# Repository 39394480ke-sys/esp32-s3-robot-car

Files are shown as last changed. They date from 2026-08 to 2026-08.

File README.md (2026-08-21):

# ESP32-S3 Robot Car

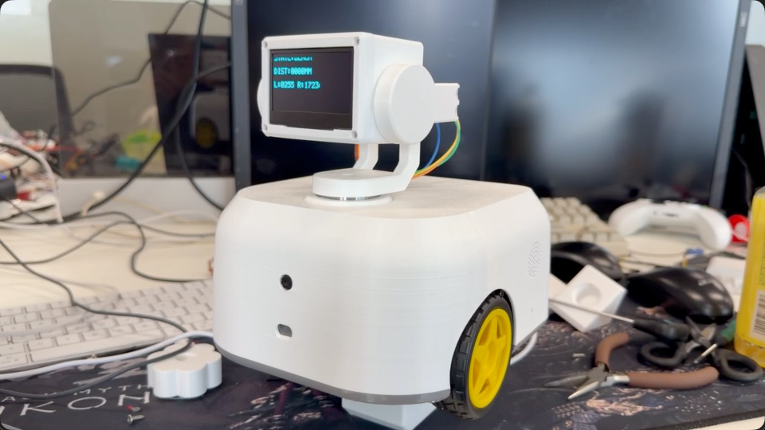
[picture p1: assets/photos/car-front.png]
ESP32-S3 小车实物正面


这是当前 ESP32-S3 双轮机器人小车的硬件与机械基线资料库，用于后续重新开发控制软件。仓库记录已经装配过的实物、供电与接口、机械装配、接线方法和硬件验证结论。

## 仓库范围

本仓库包含：

- ESP32-S3、传感器、执行器和供电模块清单
- 电源分配、GPIO、接口和接线关系
- 底盘、外壳、云台及内部模块装配说明
- 完整 STEP 装配文件和实物照片
- 已验证的硬件状态、遗留问题和安全注意事项

本仓库包含阶段 A 的整车控制固件基础。`firmware/robot_control` 当前实现电机命令、安全停止、控制 watchdog、Wi-Fi、Web 遥控、软件急停、双轴云台、OLED 表情和固定短句 TTS；编码器与 AI 尚未接入。STEP 是机械几何的权威来源；未提供的材料、紧固件、尺寸工程图和打印参数不会在文档中推测补全。

## 硬件概览

| 子系统 | 当前配置 |
|---|---|
| 主控 | ESP32-S3 开发板 |
| 驱动 | TB6612 双路直流电机驱动 |
| 行走机构 | 2 个 6Pin 霍尔编码器 TT 电机及轮组 |
| 视觉 | OV3660 FPC 摄像头 |
| 云台 | 2 个 SG90，分别控制 Yaw 和 Pitch |
| 传感器 | TOF、MPU6050、INMP441 |
| 人机交互 | 2.42 英寸 SSD1309 OLED、TTS 模块、4Ω 3W 3070 扬声器 |
| 电源 | 12V 主电源，分别降压为 6V 和 5V；主控提供 3V3 逻辑电源 |
| 结构 | 双轮底盘、打印外壳、顶部双轴云台及显示器外壳 |

## 文档导航

- [硬件 BOM](docs/bom.md)
- [供电、接口与接线](docs/wiring.md)
- [机械装配与布线](docs/assembly.md)
- [硬件验证状态](docs/validation.md)
- [阶段 A 整车控制固件](firmware/robot_control/README.md)
- [机械 CAD 说明](mechanical/README.md)
- [高清接线图](assets/diagrams/wiring-overview.png)

## 实物视图

| 外形视图 | 内部原型接线 |
|---|---|
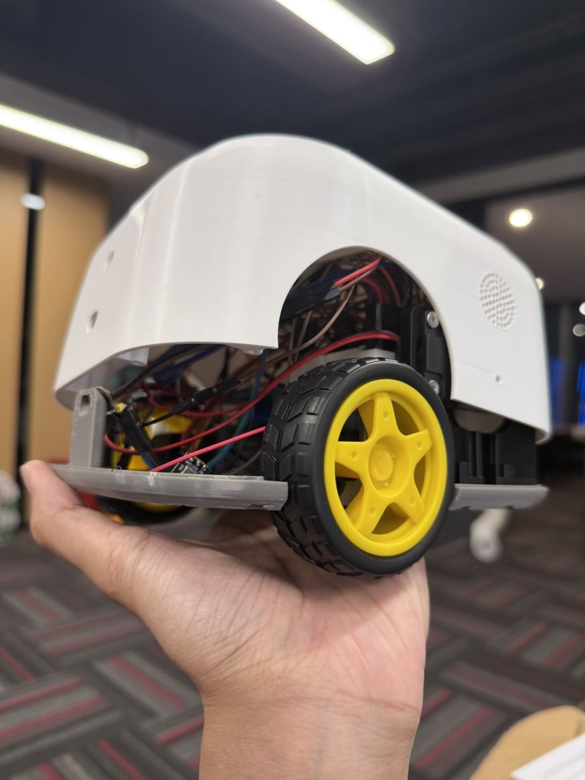
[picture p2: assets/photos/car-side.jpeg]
小车侧后视图
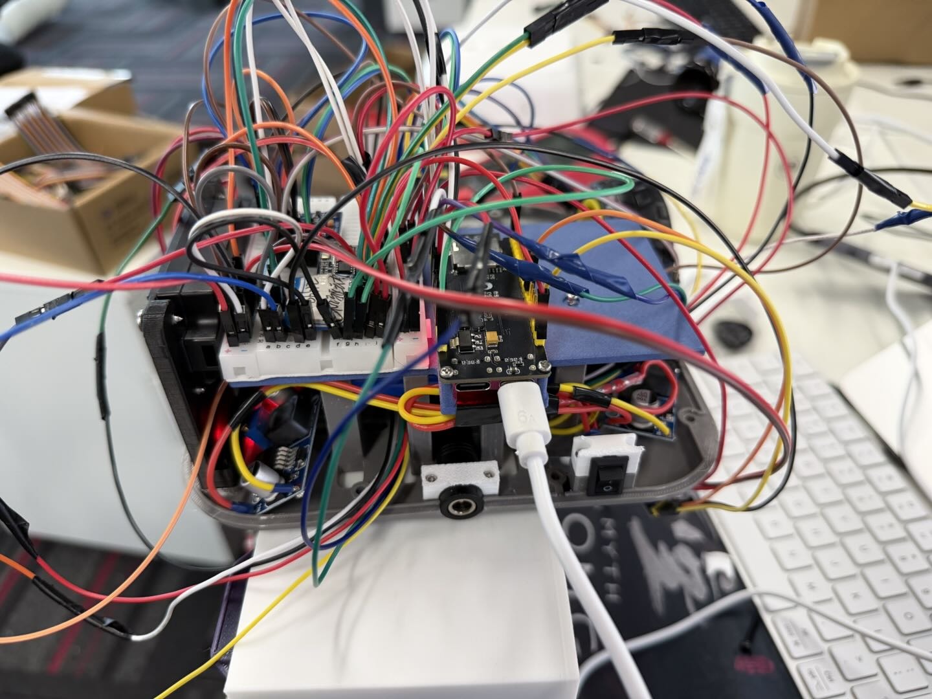
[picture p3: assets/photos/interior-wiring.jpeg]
小车内部接线
|  |  |

内部照片记录的是调试阶段的面包板与杜邦线接线，不应视为适合长期振动环境的最终线束方案。

## 首要安全规则

1. 断电状态下接线或调整 FPC，任何模块异常发热、异味或冒烟都应立即断电。
2. 12V 只进入两个降压模块的输入端，不能直接进入 ESP32-S3、传感器或面包板信号区。
3. LM2596-A 输出约 6V，仅供 TB6612 的 `VM`；LM2596-B 输出约 5V，供主控、TTS 和舵机。
4. 所有模块必须共地，但 3V3、5V、6V、12V 不得互连。
5. 电机与舵机初次上电时固定车体或架空车轮，避免车辆突然移动。

## 权利声明

当前仓库未附加开源许可证，默认保留全部权利。

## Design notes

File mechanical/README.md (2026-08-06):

# 机械 CAD

## 权威装配文件

[下载 ESP32-S3 Robot Car STEP 装配](cad/esp32-s3-robot-car.step)

| 属性 | 值 |
|---|---|
| 格式 | ISO 10303-21 / STEP AP214 |
| 单位 | 毫米 |
| 导出工具 | SolidWorks 2025 / SwSTEP 2.0 |
| 文件内时间 | 2026-06-09 09:10:46 |
| 文件大小 | 7,039,422 bytes |
| SHA-256 | `80d3d74306133b9f6671a1fcf6ae2fc44c2dd9ed444153fbde0ecb31b5fb2868` |

外部文件名已经统一为英文，STEP 内部仍保留原装配中的中文和历史零件名，以避免改变装配数据。

## 装配内容

文件包含 18 个产品定义、17 个装配关系和 20 个封闭实体。装配树中可以识别的主要对象包括：

- 整车与底盘/外壳装配
- 底盘外壳和扬声器相关结构
- 顶部云台支撑与云台盖
- 2 个 SG90 舵机
- OLED/显示器外壳相关对象
- 电源开关

部分内部名称来自早期建模或供应商模型，例如 `eBom-FreeParts`、`kaa10xlo` 和多层“装配体”名称。它们保留在 STEP 中，本仓库不根据名称猜测其准确物料身份。

## 打开与使用

1. 使用支持 STEP AP214 装配的 CAD 软件打开文件。
2. 导入单位保持毫米，不要根据屏幕显示自动缩放实体尺寸。
3. 首次打开后检查上盖、底盘、轮组、云台、OLED 外壳和开关等主要实体是否可见。
4. 二次设计时以 STEP 几何为基准另存新文件，保留本文件作为当前实物基线。

## 未包含的制造资料

当前资料没有独立提供：

- 尺寸工程图和公差
- 3D 打印材料、层高、壁厚、填充率和支撑策略
- 紧固件、隔离柱及热熔螺母规格
- 分件 STL/3MF 和切片工程
- 完整装配 BOM 与采购料号

这些项目不能仅凭照片可靠还原，应在后续拆机测量或原 CAD 设计文件可用时补充。

## 实物对照

整车外形

侧后结构

内部装配与接线

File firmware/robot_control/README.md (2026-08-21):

# Stage A Robot Control + Stage B Desktop Idle

This is the unified ESP-IDF firmware foundation for Stage A and the bounded
Stage B Desktop Idle increment. The firmware implements the frozen motor
wiring, movement capability API, safe
stop behavior, an 800 ms command watchdog, Wi-Fi STA, Web control, and a
runtime-latched emergency stop. It also includes bounded two-axis gimbal
control, reusable look/gesture capability APIs, and SSD1309 expression
rendering. Fixed UTF-8 phrases can be sent to the existing UART TTS module.
When enabled, Desktop Idle starts after 30 seconds without a user command and
adds low-frequency expression changes and small center-relative gimbal motion.

## Implemented boundary

- ESP32-S3 target using ESP-IDF 5.5.3
- TB6612 open-loop motor control at 20 kHz, 10-bit PWM
- `STOP`, `FORWARD`, `BACKWARD`, `TURN_LEFT`, and `TURN_RIGHT`
- speed input from 0 through 100 percent; the Web UI default is 40 percent
- immediate software stop on explicit STOP, invalid input, zero speed, driver
  error, Wi-Fi disconnect notification, or command timeout
- Wi-Fi reconnect with IP, RSSI, disconnect, and reconnect status
- touch, mouse, WASD, arrow-key, and Space control from one responsive page
- runtime E-stop that rejects movement until an explicit Clear
- 50 Hz SG90 control on GPIO1/GPIO2 with requested angles clamped to
  conservative configured bounds
- Web sliders for direct Yaw and Pitch control
- Web Pitch commands are throttled to the latest position every 40 milliseconds
  so continuous dragging remains responsive without irregular debounce jumps
- eight vector-rendered OLED expressions selected through one capability API
- four fixed TTS phrases over UART1 at 9600 baud on GPIO38/GPIO39
- one unified robot snapshot containing uptime, Wi-Fi, motion, safety, gimbal,
  OLED, TTS, mode, and Desktop Idle state; `/status` reads only this aggregation
  boundary
- `MANUAL` and `DESKTOP_IDLE` modes, with Desktop Idle enabled by default
- automatic Idle entry after 30 seconds without a Web command while stopped
- Idle-only OLED changes among `idle`, `curious`, `sleepy`, and `watching`
  every 20–60 seconds
- Idle gimbal gestures every 15–45 seconds, limited to center-relative
  10-degree Yaw or 8-degree upward Pitch motion and a 1.5-second hold
- synchronous manual cancellation that returns an active Idle gesture to the
  configured center before the requested manual command proceeds
- E-stop cancellation that holds the current servo position and prevents new
  Idle entries and gestures while E-stop remains active
- a Web Desktop Idle ON/OFF control plus current mode and Idle action display

The firmware boots with both PWM outputs at zero and all four TB6612 direction
signals low. `app_main` does not issue any movement command.

## Frozen hardware boundary

| Side | PWM | IN1 | IN2 |
|---|---:|---:|---:|
| Left | GPIO40 | GPIO41 | GPIO42 |
| Right | GPIO45 | GPIO46 | GPIO48 |

| Gimbal axis | PWM | Minimum | Center | Maximum |
|---|---:|---:|---:|---:|
| Yaw | GPIO1 | 45 degrees | 90 degrees | 135 degrees |
| Pitch | GPIO2 | 60 degrees | 90 degrees | 120 degrees |

TB6612 `STBY` remains connected directly to 3V3. No wiring changes are part of
this increment. Logical forward defaults to `IN1=1, IN2=0` on both sides. The
`ROBOT_LEFT_MOTOR_INVERTED` and `ROBOT_RIGHT_MOTOR_INVERTED` Kconfig options can
reverse either side without changing the wiring or capability API. The right
motor option is enabled for the installed vehicle based on its observed wheel
polarity.

The limits are Kconfig values and both axes have independent output inversion
options. They remain deliberately narrower than the nominal SG90 range until
the installed mechanism is verified.

The 128x64 SSD1309 shares GPIO47/GPIO21 with the I2C bus. Normal I2C at 0x3C or
0x3D is attempted first; the installed module does not ACK, so the driver falls
back to its vendor-compatible open-drain bit-bang protocol at 0x3C. The
firmware renders faces from a local framebuffer and does not expose pixel
drawing to callers.

Camera, PSRAM, encoders, and AI are not initialized or implemented here.
`CONFIG_SPIRAM` remains disabled because the installed
encoder signals use GPIO35, GPIO36, and GPIO37, which overlap the board's Octal
PSRAM bus. ESP-IDF pulls the `esp_psram` component transitively with Wi-Fi, but
the application does not enable or initialize it.

## Capability API

The public headers are in `main/`:

```c
esp_err_t robot_control_init(void);
esp_err_t robot_drive(robot_motion_command_t command, uint8_t speed_percent);
esp_err_t robot_move_forward(uint8_t speed_percent);
esp_err_t robot_move_backward(uint8_t speed_percent);
esp_err_t robot_turn_left(uint8_t speed_percent);
esp_err_t robot_turn_right(uint8_t speed_percent);
void robot_stop(void);
void robot_notify_wifi_disconnected(void);
void robot_estop_activate(void);
void robot_estop_clear(void);
bool robot_estop_is_active(void);
robot_state_snapshot_t robot_state_get_snapshot(void);
robot_status_snapshot_t robot_state_get_full_snapshot(void);

esp_err_t desktop_idle_init(void);
esp_err_t desktop_idle_set_enabled(bool enabled);
void desktop_idle_record_user_activity(void);
desktop_idle_snapshot_t desktop_idle_get_snapshot(void);

esp_err_t servo_control_init(void);
esp_err_t servo_set_yaw(int16_t angle);
esp_err_t servo_set_pitch(int16_t angle);
esp_err_t look_center(void);
esp_err_t look_left(void);
esp_err_t look_right(void);
esp_err_t look_up(void);
esp_err_t look_down(void);
esp_err_t nod(void);
esp_err_t shake_head(void);

esp_err_t oled_ui_init(void);
esp_err_t oled_set_expression(const char *expression_name);

esp_err_t tts_control_init(void);
esp_err_t tts_speak(const char *text);
esp_err_t tts_play_phrase(tts_phrase_id_t phrase);
```

Every accepted non-STOP movement command refreshes the watchdog. The Web page
repeats the active command every 200 ms. STOP and error paths disarm the
watchdog; they never preserve a previous movement. E-stop remains active across
page refresh and Wi-Fi reconnect, but intentionally clears after an ESP32
reboot.

## Wi-Fi and HTTP

Create an ignored `sdkconfig.local` before configuring the project:

```text
CONFIG_ROBOT_WIFI_SSID="your-ssid"
CONFIG_ROBOT_WIFI_PASSWORD="your-password"
```

The firmware never logs the configured password. If a generated `sdkconfig`
already exists when credentials change, remove or update that ignored generated
file before rebuilding so ESP-IDF reapplies the local defaults.

The unauthenticated LAN API is:

```text
GET  /
GET  /status
POST /api/drive?command=forward|backward|left|right&speed=0..100
POST /api/stop
POST /api/estop
POST /api/estop/clear
POST /api/servo?axis=yaw|pitch&angle=degrees
POST /api/oled?expression=idle|happy|curious|confused|sleepy|watching|warning|excited
POST /api/tts?phrase=hello|here|received|stopped
POST /api/idle?enabled=true|false
```

An E-stop-blocked drive request returns HTTP 409. Invalid input returns HTTP
400 and stops the motors. `GET /status` includes the stable robot ID, uptime,
Wi-Fi and RSSI, motion and safety state, `mode`, `idle_enabled`, `idle_action`,
gimbal angles, OLED expression, TTS state, and current/minimum free heap.
`tts_busy` means the firmware is
transmitting a command to the TTS module; the installed module does not provide
verified playback-completion feedback.

## Build and host tests

Run from an initialized ESP-IDF 5.5.3 shell:

```sh
cd firmware/robot_control
idf.py build
./tests/run_host_tests.sh
```

The host test uses a fake motor backend. It verifies command routing, direction
policy, speed boundaries, stop reasons, driver failure, Wi-Fi disconnect,
E-stop locking and clearing, and the watchdog boundary at 799/800 ms. The
policy tests also cover the exact 30-second Idle boundary, E-stop/motion gates,
15–45 second delay bounds, and center-relative servo clamping. The protocol
tests cover OLED expression IDs and TW-TTS UTF-8 framing. The contract test
checks the HTTP routes, Desktop Idle fields and control, fixed Web controls,
and browser release safeguards.

The Step 19 combination run exercises all six runtime modules for 30 minutes.
Every ten-second cycle drives at 50 percent with 200 ms keep-alive commands,
changes the OLED expression, moves both servo axes inside their configured
limits, checks `/status`, and explicitly stops. A fixed TTS phrase is sent every
ten cycles. The final cleanup stops the motors, centers the gimbal, and restores
the idle expression.

## Evidence status

- **Verified by repository state:** documented GPIO assignment and the prior
  hardware validation record.
- **User-observed:** both motors and normal vehicle movement worked in earlier
  projects. During this increment, with the wheels raised, movement occurred at
  50 percent and the wheels stopped after each explicit STOP; no movement was
  observed at 20 percent. A later, more specific observation found that the
  software Right command produced Forward and Backward produced Left, indicating
  reversed right-motor polarity. After enabling right-motor inversion, the user
  tested the overall controls and reported no remaining problem.
  The earlier installed gimbal used a 127-degree mechanical Yaw center. During
  a later horn reset, Yaw output was reversed and the position reached by the
  old 104-degree command became the new installed center. A +14-degree trim now
  maps that mechanical position to 90 degrees in the Web/API coordinate system.
  The installed SSD1309 displayed the
  default face, and all eight expressions switched correctly from the Web UI.
  The installed TTS module and speaker clearly played all four fixed Chinese
  phrases.
- **Verified in this increment:** ESP-IDF 5.5.3 build and flash, Wi-Fi
  connection, HTTP status, STOP, E-stop/Clear, E-stop rejection, invalid request
  rejection, and host-side safety behavior. The automated 30-minute combination
  run completed 180 cycles with zero HTTP/control failures, zero resets, and no
  additional Wi-Fi disconnect. Uptime advanced continuously, sampled free heap
  started and ended at about 261.5 KiB (lowest sampled value about 261.2 KiB),
  and the robot finished in STOP with Yaw/Pitch centered and the idle expression.
- **Verified for Stage B by machine output and API state:** ESP-IDF 5.5.3 host
  tests and full firmware build passed; the firmware flashed successfully to
  the connected ESP32-S3. Serial logs recorded automatic `DESKTOP_IDLE` entry
  at about 30.9 seconds and later recorded bounded `LOOK_LEFT` and `LOOK_UP`
  actions. During `LOOK_UP`, a manual OLED request produced an immediate Idle
  cancellation log; `/status` then reported `MANUAL`, action `NONE`, centered
  Yaw/Pitch, and the requested expression. E-stop remained active for about 58
  seconds with no new Idle action in the serial log, while `/status` continued
  to report stopped motors, `MANUAL`, and action `NONE`. Idle OFF and ON API
  requests both succeeded and the disabled state appeared in `/status`.
- **Unverified in this increment:** braking distance under floor load, movement
  from the browser UI, physical watchdog/E-stop stopping, established-link
  Wi-Fi reconnection, the exact motor startup threshold, installed gimbal
  endpoint clearance/direction semantics and gesture motion. API success during
  the combination run does not by itself verify the physical wheel, servo,
  display, or speaker behavior; that requires the user's direct observation.
- **Still unverified for Stage B:** long-duration reset and heap stability plus
  servo temperature over the planned two-hour run.
- **User-observed for Stage B:** after the Stage B firmware was flashed, the
  user confirmed the physical behavior was satisfactory, covering the visible
  Idle expressions, small gimbal gestures and return, manual interruption, and
  lack of motor motion during the observed Idle period.
- **Explicitly waived:** the user chose to skip the planned two-hour stability
  and servo-temperature validation. Long-duration reset, heap, and thermal
  behavior therefore remains unverified and is not claimed as passed.

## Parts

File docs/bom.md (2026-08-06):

# 硬件 BOM

本表描述当前实物基线。`未提供` 表示现有资料不足，不代表该项目不需要该参数。

## 电子与机电部件

| 类别 | 部件 | 数量 | 已知规格或用途 | 尚未提供的信息 |
|---|---|---:|---|---|
| 主控 | ESP32-S3 开发板 | 1 | 带 USB 和匹配 OV3660 FPC 的摄像头接口 | 开发板准确型号、Flash/PSRAM 容量 |
| 电机驱动 | TB6612 模块 | 1 | 双路直流电机驱动，3V3 逻辑、6V 电机电源 | 模块厂牌、持续电流版本 |
| 行走电机 | 6Pin 霍尔编码器 TT 电机 | 2 | 接口顺序 `M- / M+ / V / H2 / H1 / G` | 减速比、额定转速、编码器脉冲数 |
| 轮组 | 黄色 TT 轮 | 2 | 与 TT 电机配套 | 直径、胎宽、材料 |
| 降压模块 | LM2596 | 2 | A 路输出 6V；B 路输出 5V | 模块厂牌、实际额定电流 |
| 主电源 | 12V 电源或电池 | 1 | 同时输入两个 LM2596 | 容量、最大放电电流、连接器型号 |
| 显示 | SSD1309 OLED | 1 | 2.42 英寸，3V3，I2C 基线接法 | 模块厂牌、精确分辨率版本 |
| 姿态传感器 | MPU6050 | 1 | 3V3，I2C，地址基线为 `0x68` | 模块厂牌 |
| 距离传感器 | TOF 模块 | 1 | 3V3，I2C，地址基线为 `0x29` | 具体芯片/模块型号 |
| 摄像头 | OV3660 FPC 摄像头 | 1 | 与 ESP32-S3 板载摄像头座直接连接 | FPC 触点方向图、镜头参数 |
| 云台舵机 | SG90 | 2 | Yaw 和 Pitch 各 1 个，5V 供电 | 厂牌、可靠机械行程 |
| 麦克风 | INMP441 | 1 | 3V3，I2S 数字麦克风 | 模块厂牌 |
| 语音模块 | TTS 模块 | 1 | 5V，UART，9600 波特率基线 | 准确型号、协议版本 |
| 扬声器 | 3070 腔体扬声器 | 1 | 4Ω 3W，2P2.0，两线连接 | 厂牌 |
| 原型转接 | 面包板 | 1 | 低压信号与 5V 执行器转接 | 规格 |
| 电源控制 | 船型开关 | 1 | 安装在底盘侧面 | 额定电压、电流、开孔尺寸 |

## 机械件与耗材

| 部件 | 数量 | 当前资料状态 |
|---|---:|---|
| 底盘、上盖、云台支撑、显示器外壳等打印件 | 1 套 | 几何见 [STEP 装配](../mechanical/cad/esp32-s3-robot-car.step)；材料和打印参数未提供 |
| 紧固件、隔离柱、螺母 | 未提供 | STEP 中有孔位与装配几何，但没有独立紧固件规格表 |
| 杜邦线、端子线、较粗电机线 | 按需 | 长度、线径和端子型号未提供 |
| 扎带、绝缘胶带、热缩管或固定胶 | 按需 | 用于绝缘、分束和应力释放 |

## 配套工具

- 万用表：调节 6V/5V 输出并检查短路、共地和极性。
- 小螺丝刀：调整 LM2596 电位器及紧固接线端子。
- 标签纸或美纹纸：给电源、信号和左右轮线束两端做标记。
- 镊子或尖嘴钳：整理狭小空间中的连接线。

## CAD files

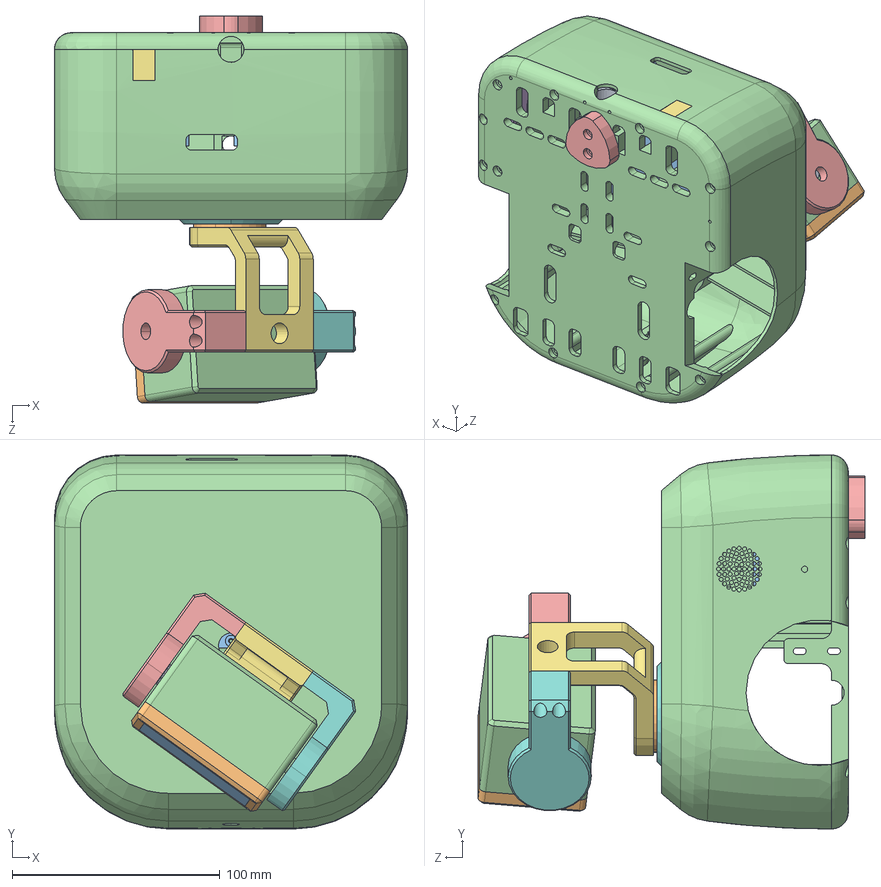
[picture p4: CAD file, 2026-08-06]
mechanical/cad/esp32-s3-robot-car.step
170.0 x 180.0 x 186.2 mm
SG90_Servo.step_1
云台盖子.step_1
oled_1
云台小电脑.step_1
零件14_总装配体_1
kaa10xlo_1
SG90_Servo.step-0_1
eBom-FreeParts_1
小车外壳 底盘 5.27.step-0_1
底盘外壳与扬声器模块_1
开关.step
云台支撑.STEP
eBom-FreeParts-0

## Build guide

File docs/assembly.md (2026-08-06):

# 机械装配与布线

本文记录当前实物的装配基线。所有形状、孔位和零件相对位置应以 [STEP 装配](../mechanical/cad/esp32-s3-robot-car.step) 为准。

整车侧后外形

## 结构组成

- 双轮 TT 电机底盘和底部支撑结构
- 圆角上盖与左右轮避让开口
- 顶部双轴 SG90 云台
- 云台显示器外壳及摄像/传感部件安装区域
- 侧面扬声器孔、开关和接口开口
- 底盘内部电子模块安装空间

现有资料没有给出打印材料、层高、壁厚、填充率、支撑策略、螺钉规格或尺寸工程图，不应根据照片推断这些制造参数。

## 内部布局基线

底盘内部原型接线

| 区域 | 建议安装对象 | 目的 |
|---|---|---|
| 底部或后部 | 12V 电源、两个 LM2596、TB6612 | 降低重心，缩短大电流路径并便于散热 |
| 中部 | ESP32-S3、面包板或转接板 | 保留 USB 和调试接口的可达性 |
| 前部/上层 | TOF、OV3660、OLED、双轴云台 | 保证视野、测距方向和显示可读性 |
| 侧面开口 | 船型开关、扬声器 | 对齐 STEP 中对应开孔并避免压线 |
| 远离噪声处 | INMP441 | 减少电机、降压模块和扬声器干扰 |

照片中的面包板和散开的杜邦线属于调试状态。重新开发时应优先改为有锁连接器、定长线束和可靠的应力释放，不要让松散线束接触轮胎、舵机或外壳边缘。

## 推荐装配顺序

1. 在 CAD 中确认底盘、上盖、云台支撑、显示器外壳和开关等零件齐全，导入单位保持毫米。
2. 安装左右 TT 电机与轮组，确认两侧轮胎自由转动且不会摩擦外壳开口。
3. 固定电池、LM2596 和 TB6612，保留 LM2596 调压位置并缩短电池至驱动板的线长。
4. 固定 ESP32-S3 与转接板，使 USB 口、开关和必要的维护接口在合壳后仍可接近。
5. 在安装舵机摇臂前，用舵机测试器或等效方法使两个 SG90 位于机械中位，再分别装入 Yaw/Pitch 结构。
6. 安装 OLED、OV3660、TOF、扬声器和麦克风，检查视野、声孔和外壳开孔没有遮挡。
7. 按电源、执行器、传感器、摄像头四类整理线束，完成后再安装上盖。
8. 合壳前进行连续性、电压、温升、轮组和云台干涉检查。

## 线束分区

| 线束类别 | 包含线路 | 布线要求 |
|---|---|---|
| 主电源 | 12V、6V、5V 和公共地 | 线径与电流匹配，极性清楚，接头固定 |
| 电机动力 | TB6612 到左右 `M+/M-` | 尽量短，可轻绞，远离传感器线 |
| 编码器与传感器 | H1/H2、I2C、I2S | 与电机动力线分开，避免悬空和拉扯 |
| 云台 | 5V、GND、Yaw、Pitch | 在穿出上盖处做应力释放并保留运动余量 |
| 摄像头 | OV3660 FPC | 保持自然弯曲半径，不折死角、不被壳体夹住 |

面包板可按左侧 3V3 逻辑/传感器区、右侧 5V 执行器区分配；左右只桥接 GND，不连接 3V3 与 5V。6V 电机电源不建议长期经过面包板弹片。

## 合壳检查

- 轮胎与外壳保持间隙，手动转动没有卡滞。
- 云台在允许行程内不会撞壳、拉扯线束或压住摄像头排线。
- TOF 和摄像头前方没有外壳边缘、线束或紧固件遮挡。
- 扬声器与侧面声孔对齐，线束不接触振膜。
- USB、开关及维护连接器可以操作。
- 所有电路板和接头固定，晃动车体时不会移动或松脱。
- 上盖闭合后没有夹线，底盘内没有裸露的 12V 导体。

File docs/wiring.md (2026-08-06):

# 供电、接口与接线

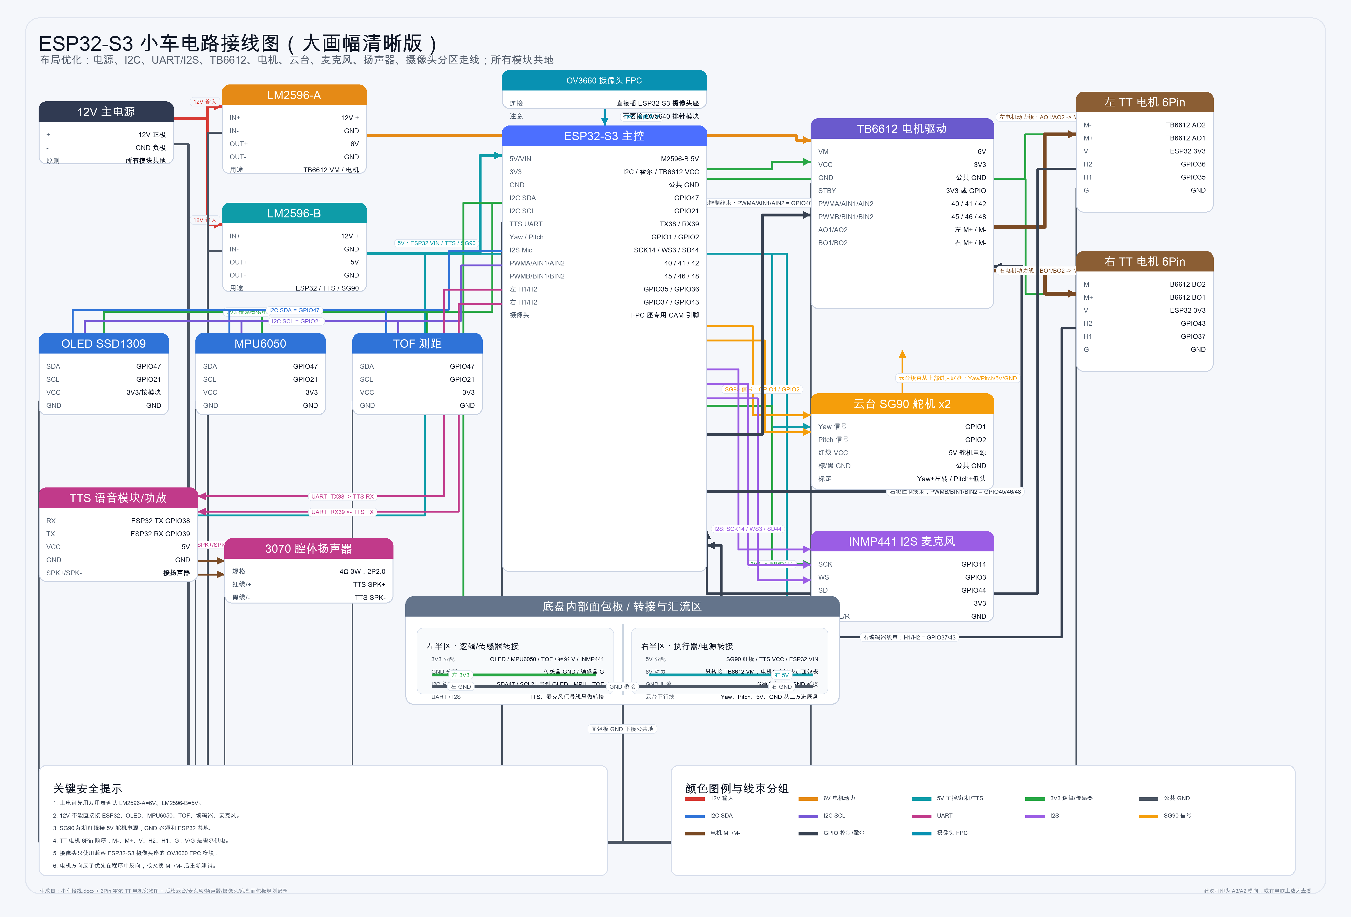
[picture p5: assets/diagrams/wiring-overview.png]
ESP32-S3 小车高清接线图


> 接线图是整车关系总览，下面的表格用于逐项核对。摄像头按当前实物确认的 OV3660 记录。

## 电源域

| 电源节点 | 来源 | 连接对象 | 注意事项 |
|---|---|---|---|
| 12V | 主电源正极 | LM2596-A/B 的 `IN+` | 不进入 ESP32-S3、传感器或普通面包板电源排 |
| 6V | LM2596-A `OUT+` | TB6612 `VM` | 只作为 TT 电机动力电源 |
| 5V | LM2596-B `OUT+` | ESP32-S3 `5V/VIN`、TTS、两个 SG90 | 舵机启动电流较大，导线和降压能力需要留余量 |
| 3V3 | ESP32-S3 `3V3` | TB6612 `VCC/STBY`、OLED、MPU6050、TOF、编码器 `V`、INMP441 | 只供逻辑与小功率模块 |
| GND | 12V 负极和所有电源负端 | 全部模块 | 所有模块共地，建议设置明确的公共地汇流点 |

### 调压顺序

1. 断开所有后级负载，只给两个 LM2596 接入 12V。
2. 测量 `OUT+` 与 `OUT-`，把 A 路调到约 6.0V。
3. 把 B 路调到约 5.0V。
4. 断电后再连接 TB6612、ESP32-S3 和外设。
5. 首次上电观察模块温度，并复测各电源域对 GND 的电压。

## GPIO 与通信接口

| 子系统 | 信号 | ESP32-S3 GPIO | 外设端 |
|---|---|---:|---|
| 左电机 | PWM | GPIO40 | TB6612 `PWMA` |
| 左电机 | 方向 1/2 | GPIO41 / GPIO42 | TB6612 `AIN1/AIN2` |
| 右电机 | PWM | GPIO45 | TB6612 `PWMB` |
| 右电机 | 方向 1/2 | GPIO46 / GPIO48 | TB6612 `BIN1/BIN2` |
| 左编码器 | H1/H2 | GPIO35 / GPIO36 | 左 TT 电机 `H1/H2` |
| 右编码器 | H1/H2 | GPIO37 / GPIO43 | 右 TT 电机 `H1/H2` |
| I2C | SDA/SCL | GPIO47 / GPIO21 | OLED、MPU6050、TOF 共线 |
| TTS UART | ESP TX / ESP RX | GPIO38 / GPIO39 | TTS `RX/TX`，交叉连接 |
| 云台 | Yaw/Pitch | GPIO1 / GPIO2 | 两个 SG90 信号线 |
| INMP441 | SCK/WS/SD | GPIO14 / GPIO3 / GPIO44 | I2S 时钟、帧同步、数据 |

## TB6612 与 TT 电机

TB6612 的 `VM` 与 `VCC` 是不同电源：`VM` 接 6V，`VCC` 接 3V3，`STBY` 在当前基线中建议直接拉到 3V3。

| 电机接口 | 含义 | 左侧连接 | 右侧连接 |
|---|---|---|---|
| `M-` | 电机动力端 | TB6612 `AO2` | TB6612 `BO2` |
| `M+` | 电机动力端 | TB6612 `AO1` | TB6612 `BO1` |
| `V` | 霍尔编码器正极 | 3V3 | 3V3 |
| `H2` | 霍尔信号 2 | GPIO36 | GPIO43 |
| `H1` | 霍尔信号 1 | GPIO35 | GPIO37 |
| `G` | 霍尔编码器负极 | GND | GND |

不同批次 TB6612 模块的排针顺序可能不同，必须按实物丝印核对。若轮子方向不符合机械前进方向，可交换该电机 `M+ / M-`；编码器方向则由 `H1/H2` 相位定义，应独立核对。

## I2C 模块

OLED、MPU6050 和 TOF 共用 GPIO47/GPIO21。三者使用 3V3 和公共 GND，不得连接 5V、6V 或 12V。已确认的基线地址为 TOF `0x29`、MPU6050 `0x68`；OLED 曾经能够正常显示，但不保证在通用地址扫描中始终应答。

## TTS、扬声器、舵机与麦克风

- ESP32-S3 GPIO38 发送到 TTS `RX`，GPIO39 接收 TTS `TX`。
- 3070 扬声器只接 TTS 或功放的 `SPK+ / SPK-`，不能直接接 GPIO 或电源脚。
- 两个 SG90 的红线接 5V，棕/黑线接 GND，Yaw/Pitch 信号分别接 GPIO1/GPIO2。
- INMP441 的 `VDD` 接 3V3，`GND` 接公共地，`SCK/WS/SD` 分别接 GPIO14/GPIO3/GPIO44，单麦克风基线中 `L/R` 接 GND。

## OV3660 摄像头接口

当前实物使用与 ESP32-S3 开发板摄像头座匹配的 OV3660 FPC 模块。应在断电状态下插拔，金手指方向和锁扣必须按开发板摄像头座确认。不要根据 GPIO 表直接给裸 FPC 飞线。

| 摄像头信号 | GPIO | 摄像头信号 | GPIO |
|---|---:|---|---:|
| SIOD | 4 | SIOC | 5 |
| VSYNC | 6 | HREF | 7 |
| XCLK | 15 | PCLK | 13 |
| Y2 | 11 | Y3 | 9 |
| Y4 | 8 | Y5 | 10 |
| Y6 | 12 | Y7 | 18 |
| Y8 | 17 | Y9 | 16 |

这些 GPIO 描述的是当前开发板基线，不等同于 FPC 触点编号。更换开发板或转接板时必须重新核对原理图和丝印。

## 上电前核对

- 12V 正极与 GND 不短路，电源极性正确。
- A 路约 6V，B 路约 5V，ESP32-S3 的 3V3 输出正常。
- TB6612 `VM=6V`、`VCC=3V3`、`STBY` 为高电平且 GND 共地。
- 5V、6V、3V3 电源排之间不导通。
- 摄像头 FPC 插到底、锁扣闭合、没有死折或被外壳压住。
- 电机动力线远离 I2C、I2S 和摄像头排线。

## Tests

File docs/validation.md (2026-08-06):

# 硬件验证状态

本页只保留实物和电气层面的验证结论，不记录固件模式、算法参数或软件调试过程。状态代表这套硬件曾经达到过的结果，拆装或重新接线后仍需复测。

## 已观察结果

| 模块 | 状态 | 实物结论 |
|---|---|---|
| ESP32-S3 | 通过 | USB 连接、供电和基本运行正常 |
| SSD1309 OLED | 通过 | 屏幕能够点亮并显示信息 |
| I2C 总线 | 通过 | 曾稳定发现 TOF `0x29` 和 MPU6050 `0x68` |
| MPU6050 | 通过 | 转动车体时加速度和角速度数据会变化 |
| TOF | 有条件通过 | 裸机时距离随遮挡变化；装壳后曾出现近距离或 0 值，需处理视窗遮挡后复测 |
| INMP441 | 通过 | 拍手或说话时采集强度明显变化 |
| OV3660 | 通过，需谨慎复测 | 摄像头曾被正确识别并能获取画面；FPC 和转接方向必须再次核对 |
| TTS + 3070 扬声器 | 通过 | 模块与扬声器链路能够发声，扬声器极性已经修正 |
| 两个 SG90 | 通过 | Yaw/Pitch 均能动作，装壳后扫描未见明显机械干涉 |
| 左右 TT 电机 | 通过 | 两侧均能转动，机械前进方向已经校准过 |
| 左右霍尔编码器 | 通过 | 手动或电机带动轮组时，两侧信号均会变化 |
| TB6612 驱动链路 | 通过 | 修正遗漏控制线和板子方向后，两路能够驱动电机 |

## 必须保留的风险记录

### TOF 视窗遮挡

装壳后 TOF 曾从可变化的读数回到持续近距离或 0 值。最可能的硬件原因是外壳边缘、线束或近距离结构进入视场。重新装配时应在合壳前后分别测量，并移动遮挡物确认变化。

### 摄像头 FPC 与温升

历史拆装中曾出现摄像头或转接区域异常发热并立即断电的情况。每次连接 OV3660 前必须确认：

- 型号与开发板摄像头座匹配
- 金手指方向正确，FPC 插到底并锁紧
- 3V3/GND 没有接反或短路
- 排线没有破损、死折或被外壳压住

首次复测应短时间上电并监测温度，异常发热立即断电。

### 原型线束可靠性

当前内部照片使用面包板、杜邦线和胶带连接，适合桌面验证，不适合长期振动。重新开发时应把以下项目作为硬件升级重点：

- 电机、舵机和电池使用有锁连接器及合适线径
- 电源入口增加保险或过流保护
- 关键线束做应力释放和两端标签
- 逻辑线与电机动力线分束
- 电路板使用隔离柱或可靠支架固定

### TB6612 模块差异

历史问题包括控制线遗漏和模块方向理解错误。不同 TB6612 小板的排针次序可能不一致，必须以实物丝印为准，并分别测量 `VM`、`VCC`、`STBY` 与 GND。

### 编码器方向

两侧编码器信号都已验证存在，但右侧计数方向曾与左侧符号相反。这不代表编码器损坏；重新开发时需要统一机械前进方向、`M+/M-` 极性和 `H1/H2` 相位定义。

## 重新接线后的最小复测顺序

1. 断电检查 12V 正极与 GND 是否短路。
2. 断开负载，分别测量 LM2596-A 约 6V、LM2596-B 约 5V。
3. 接入 ESP32-S3，确认 5V 输入、3V3 输出和板载温度正常。
4. 检查 OLED、MPU6050、TOF、INMP441、TTS 和 OV3660 的供电及基本响应。
5. 确认两个 SG90 的中位、行程和线束余量。
6. 架空车轮，分别确认左右电机方向和编码器信号。
7. 合壳后再次确认 TOF 视场、OV3660 画面、OLED 可视性和所有机械间隙。

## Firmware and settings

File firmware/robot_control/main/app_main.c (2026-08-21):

#include "esp_log.h"

#include "desktop_idle.h"
#include "oled_ui.h"
#include "robot_control.h"
#include "servo_control.h"
#include "tts_control.h"
#include "web_server.h"
#include "wifi_manager.h"

static const char *TAG = "robot_main";

void app_main(void)
{
    ESP_LOGI(TAG, "Stage B desktop idle initialization");
    const esp_err_t result = robot_control_init();
    if (result != ESP_OK) {
        ESP_LOGE(TAG,
                 "robot control initialization failed: %s; motors remain stopped",
                 esp_err_to_name(result));
        return;
    }

    const esp_err_t servo_result = servo_control_init();
    if (servo_result != ESP_OK) {
        robot_stop();
        ESP_LOGE(TAG,
                 "gimbal initialization failed: %s; motors remain stopped",
                 esp_err_to_name(servo_result));
        return;
    }

    const esp_err_t oled_result = oled_ui_init();
    if (oled_result != ESP_OK) {
        robot_stop();
        ESP_LOGW(TAG,
                 "OLED initialization failed: %s; continuing with OLED unavailable",
                 esp_err_to_name(oled_result));
    }

    const esp_err_t tts_result = tts_control_init();
    if (tts_result != ESP_OK) {
        robot_stop();
        ESP_LOGW(TAG,
                 "TTS initialization failed: %s; continuing with TTS unavailable",
                 esp_err_to_name(tts_result));
    }

    const esp_err_t wifi_result = wifi_manager_init();
    if (wifi_result != ESP_OK) {
        robot_stop();
        ESP_LOGE(TAG,
                 "Wi-Fi initialization failed: %s; motors remain stopped",
                 esp_err_to_name(wifi_result));
        return;
    }

    const esp_err_t idle_result = desktop_idle_init();
    if (idle_result != ESP_OK) {
        robot_stop();
        ESP_LOGE(TAG,
                 "desktop idle initialization failed: %s; motors remain stopped",
                 esp_err_to_name(idle_result));
        return;
    }

    const esp_err_t server_result = web_server_start();
    if (server_result != ESP_OK) {
        robot_stop();
        ESP_LOGE(TAG,
                 "Web server initialization failed: %s; motors remain stopped",
                 esp_err_to_name(server_result));
        return;
    }

    ESP_LOGI(TAG,
             "motors stopped; desktop idle enabled; waiting for Web control commands");
}

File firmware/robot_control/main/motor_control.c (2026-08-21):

#include "motor_control.h"

#include <stdbool.h>

#include "driver/gpio.h"
#include "driver/ledc.h"
#include "sdkconfig.h"

#include "motor_policy.h"

#ifndef CONFIG_ROBOT_LEFT_MOTOR_INVERTED
#define CONFIG_ROBOT_LEFT_MOTOR_INVERTED 0
#endif

#ifndef CONFIG_ROBOT_RIGHT_MOTOR_INVERTED
#define CONFIG_ROBOT_RIGHT_MOTOR_INVERTED 0
#endif

#define LEFT_PWM_GPIO GPIO_NUM_40
#define LEFT_IN1_GPIO GPIO_NUM_41
#define LEFT_IN2_GPIO GPIO_NUM_42
#define RIGHT_PWM_GPIO GPIO_NUM_45
#define RIGHT_IN1_GPIO GPIO_NUM_46
#define RIGHT_IN2_GPIO GPIO_NUM_48

#define MOTOR_PWM_FREQUENCY_HZ 20000
#define MOTOR_PWM_MAX_DUTY ((1U << 10U) - 1U)

static const ledc_mode_t MOTOR_PWM_MODE = LEDC_LOW_SPEED_MODE;
static const ledc_timer_t MOTOR_PWM_TIMER = LEDC_TIMER_0;
static const ledc_channel_t LEFT_PWM_CHANNEL = LEDC_CHANNEL_0;
static const ledc_channel_t RIGHT_PWM_CHANNEL = LEDC_CHANNEL_1;

static bool s_initialized;

static esp_err_t preserve_first_error(esp_err_t first, esp_err_t current)
{
    return first == ESP_OK ? current : first;
}

static esp_err_t configure_safe_gpio_levels(void)
{
    const uint64_t output_mask =
        (1ULL << LEFT_PWM_GPIO) |
        (1ULL << LEFT_IN1_GPIO) |
        (1ULL << LEFT_IN2_GPIO) |
        (1ULL << RIGHT_PWM_GPIO) |
        (1ULL << RIGHT_IN1_GPIO) |
        (1ULL << RIGHT_IN2_GPIO);
    const gpio_config_t config = {
        .pin_bit_mask = output_mask,
        .mode = GPIO_MODE_OUTPUT,
        .pull_up_en = GPIO_PULLUP_DISABLE,
        .pull_down_en = GPIO_PULLDOWN_DISABLE,
        .intr_type = GPIO_INTR_DISABLE,
    };

    esp_err_t result = gpio_config(&config);
    result = preserve_first_error(result, gpio_set_level(LEFT_PWM_GPIO, 0));
    result = preserve_first_error(result, gpio_set_level(RIGHT_PWM_GPIO, 0));
    result = preserve_first_error(result, gpio_set_level(LEFT_IN1_GPIO, 0));
    result = preserve_first_error(result, gpio_set_level(LEFT_IN2_GPIO, 0));
    result = preserve_first_error(result, gpio_set_level(RIGHT_IN1_GPIO, 0));
    result = preserve_first_error(result, gpio_set_level(RIGHT_IN2_GPIO, 0));
    return result;
}

static esp_err_t set_wheel_direction(gpio_num_t in1,
                                     gpio_num_t in2,
                                     motor_wheel_direction_t direction)
{
    int first_level = 0;
    int second_level = 0;
    if (direction == MOTOR_WHEEL_FORWARD) {
        first_level = 1;
    } else if (direction == MOTOR_WHEEL_REVERSE) {
        second_level = 1;
    }

    esp_err_t result = gpio_set_level(in1, first_level);
    result = preserve_first_error(result, gpio_set_level(in2, second_level));
    return result;
}

static esp_err_t set_pwm_duty(ledc_channel_t channel, uint32_t duty)
{
    esp_err_t result = ledc_set_duty(MOTOR_PWM_MODE, channel, duty);
    if (result == ESP_OK) {
        result = ledc_update_duty(MOTOR_PWM_MODE, channel);
    }
    return result;
}

esp_err_t motor_control_stop(void)
{
    esp_err_t result = ESP_OK;
    if (s_initialized) {
        result = set_pwm_duty(LEFT_PWM_CHANNEL, 0U);
        result = preserve_first_error(
            result, set_pwm_duty(RIGHT_PWM_CHANNEL, 0U));
    } else {
        result = gpio_set_level(LEFT_PWM_GPIO, 0);
        result = preserve_first_error(
            result, gpio_set_level(RIGHT_PWM_GPIO, 0));
    }

    result = preserve_first_error(
        result, set_wheel_direction(LEFT_IN1_GPIO, LEFT_IN2_GPIO,
                                    MOTOR_WHEEL_STOP));
    result = preserve_first_error(
        result, set_wheel_direction(RIGHT_IN1_GPIO, RIGHT_IN2_GPIO,
                                    MOTOR_WHEEL_STOP));
    return result;
}

esp_err_t motor_control_init(void)
{
    s_initialized = false;
    esp_err_t result = configure_safe_gpio_levels();
    if (result != ESP_OK) {
        return result;
    }

    const ledc_timer_config_t timer_config = {
        .speed_mode = MOTOR_PWM_MODE,
        .duty_resolution = LEDC_TIMER_10_BIT,
        .timer_num = MOTOR_PWM_TIMER,
        .freq_hz = MOTOR_PWM_FREQUENCY_HZ,
        .clk_cfg = LEDC_AUTO_CLK,
        .deconfigure = false,
    };
    result = ledc_timer_config(&timer_config);
    if (result != ESP_OK) {
        return result;
    }

    const ledc_channel_config_t left_channel = {
        .gpio_num = LEFT_PWM_GPIO,
        .speed_mode = MOTOR_PWM_MODE,
        .channel = LEFT_PWM_CHANNEL,
        .intr_type = LEDC_INTR_DISABLE,
        .timer_sel = MOTOR_PWM_TIMER,
        .duty = 0U,
        .hpoint = 0,
        .sleep_mode = LEDC_SLEEP_MODE_NO_ALIVE_NO_PD,
        .flags.output_invert = 0,
    };
    const ledc_channel_config_t right_channel = {
        .gpio_num = RIGHT_PWM_GPIO,
        .speed_mode = MOTOR_PWM_MODE,
        .channel = RIGHT_PWM_CHANNEL,
        .intr_type = LEDC_INTR_DISABLE,
        .timer_sel = MOTOR_PWM_TIMER,
        .duty = 0U,
        .hpoint = 0,
        .sleep_mode = LEDC_SLEEP_MODE_NO_ALIVE_NO_PD,
        .flags.output_invert = 0,
    };
    result = ledc_channel_config(&left_channel);
    if (result == ESP_OK) {
        result = ledc_channel_config(&right_channel);
    }
    if (result != ESP_OK) {
        ledc_stop(MOTOR_PWM_MODE, LEFT_PWM_CHANNEL, 0U);
        ledc_stop(MOTOR_PWM_MODE, RIGHT_PWM_CHANNEL, 0U);
        configure_safe_gpio_levels();
        return result;
    }

    s_initialized = true;
    return motor_control_stop();
}

esp_err_t motor_control_apply(robot_motion_command_t command,
                              uint8_t speed_percent)
{
    if (!s_initialized) {
        return ESP_ERR_INVALID_STATE;
    }
    if (command == ROBOT_MOTION_STOP || speed_percent == 0U) {
        return motor_control_stop();
    }
    if (speed_percent > 100U) {
        motor_control_stop();
        return ESP_ERR_INVALID_ARG;
    }

    motor_direction_pair_t directions;
    if (!motor_policy_resolve(command,
                              CONFIG_ROBOT_LEFT_MOTOR_INVERTED,
                              CONFIG_ROBOT_RIGHT_MOTOR_INVERTED,
                              &directions)) {
        motor_control_stop();
        return ESP_ERR_INVALID_ARG;
    }

    esp_err_t result = set_pwm_duty(LEFT_PWM_CHANNEL, 0U);
    result = preserve_first_error(
        result, set_pwm_duty(RIGHT_PWM_CHANNEL, 0U));
    result = preserve_first_error(
        result, set_wheel_direction(LEFT_IN1_GPIO, LEFT_IN2_GPIO,
                                    directions.left));
    result = preserve_first_error(
        result, set_wheel_direction(RIGHT_IN1_GPIO, RIGHT_IN2_GPIO,
                                    directions.right));
    if (result != ESP_OK) {
        motor_control_stop();
        return result;
    }

    const uint32_t duty =
        ((uint32_t)speed_percent * MOTOR_PWM_MAX_DUTY + 50U) / 100U;
    result = set_pwm_duty(LEFT_PWM_CHANNEL, duty);
    result = preserve_first_error(
        result, set_pwm_duty(RIGHT_PWM_CHANNEL, duty));
    if (result != ESP_OK) {
        motor_control_stop();
    }
    return result;
}

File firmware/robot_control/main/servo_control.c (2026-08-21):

#include "servo_control.h"

#include "driver/gpio.h"
#include "driver/ledc.h"
#include "freertos/FreeRTOS.h"
#include "freertos/semphr.h"
#include "freertos/task.h"
#include "sdkconfig.h"

#ifndef CONFIG_ROBOT_YAW_INVERTED
#define CONFIG_ROBOT_YAW_INVERTED 0
#endif

#ifndef CONFIG_ROBOT_YAW_TRIM_DEGREES
#define CONFIG_ROBOT_YAW_TRIM_DEGREES 0
#endif

#ifndef CONFIG_ROBOT_PITCH_INVERTED
#define CONFIG_ROBOT_PITCH_INVERTED 0
#endif

#define YAW_GPIO GPIO_NUM_1
#define PITCH_GPIO GPIO_NUM_2
#define SERVO_PWM_FREQUENCY_HZ 50
#define SERVO_PWM_MAX_DUTY ((1U << 14U) - 1U)
#define GESTURE_DELAY_MS 220U

static const ledc_mode_t SERVO_PWM_MODE = LEDC_LOW_SPEED_MODE;
static const ledc_timer_t SERVO_PWM_TIMER = LEDC_TIMER_1;
static const ledc_channel_t YAW_PWM_CHANNEL = LEDC_CHANNEL_2;
static const ledc_channel_t PITCH_PWM_CHANNEL = LEDC_CHANNEL_3;

static const servo_axis_limits_t YAW_LIMITS = {
    .minimum = CONFIG_ROBOT_YAW_MIN_DEGREES,
    .center = CONFIG_ROBOT_YAW_CENTER_DEGREES,
    .maximum = CONFIG_ROBOT_YAW_MAX_DEGREES,
};
static const servo_axis_limits_t PITCH_LIMITS = {
    .minimum = CONFIG_ROBOT_PITCH_MIN_DEGREES,
    .center = CONFIG_ROBOT_PITCH_CENTER_DEGREES,
    .maximum = CONFIG_ROBOT_PITCH_MAX_DEGREES,
};

static SemaphoreHandle_t s_mutex;
static servo_control_snapshot_t s_state;

static esp_err_t set_axis_locked(ledc_channel_t channel,
                                 int16_t requested_angle,
                                 const servo_axis_limits_t *limits,
                                 int16_t trim,
                                 bool inverted,
                                 int16_t *stored_angle)
{
    const int16_t angle = servo_policy_clamp(requested_angle, limits);
    const int16_t calibrated_angle = servo_policy_apply_trim(angle, trim);
    const uint32_t duty =
        servo_policy_angle_to_duty(calibrated_angle, inverted, SERVO_PWM_MAX_DUTY);
    esp_err_t result = ledc_set_duty(SERVO_PWM_MODE, channel, duty);
    if (result == ESP_OK) {
        result = ledc_update_duty(SERVO_PWM_MODE, channel);
    }
    if (result == ESP_OK) {
        *stored_angle = angle;
    }
    return result;
}

static esp_err_t set_axis(ledc_channel_t channel,
                          int16_t requested_angle,
                          const servo_axis_limits_t *limits,
                          int16_t trim,
                          bool inverted,
                          int16_t *stored_angle)
{
    if (!s_state.initialized || s_mutex == NULL) {
        return ESP_ERR_INVALID_STATE;
    }
    if (xSemaphoreTake(s_mutex, portMAX_DELAY) != pdTRUE) {
        return ESP_ERR_TIMEOUT;
    }
    const esp_err_t result = set_axis_locked(channel,
                                             requested_angle,
                                             limits,
                                             trim,
                                             inverted,
                                             stored_angle);
    xSemaphoreGive(s_mutex);
    return result;
}

esp_err_t servo_control_init(void)
{
    if (YAW_LIMITS.minimum > YAW_LIMITS.center ||
        YAW_LIMITS.center > YAW_LIMITS.maximum ||
        PITCH_LIMITS.minimum > PITCH_LIMITS.center ||
        PITCH_LIMITS.center > PITCH_LIMITS.maximum) {
        return ESP_ERR_INVALID_ARG;
    }
    s_state = (servo_control_snapshot_t){
        .yaw = YAW_LIMITS.center,
        .pitch = PITCH_LIMITS.center,
        .yaw_limits = YAW_LIMITS,
        .pitch_limits = PITCH_LIMITS,
    };
    s_mutex = xSemaphoreCreateMutex();
    if (s_mutex == NULL) {
        return ESP_ERR_NO_MEM;
    }

    const ledc_timer_config_t timer = {
        .speed_mode = SERVO_PWM_MODE,
        .duty_resolution = LEDC_TIMER_14_BIT,
        .timer_num = SERVO_PWM_TIMER,
        .freq_hz = SERVO_PWM_FREQUENCY_HZ,
        .clk_cfg = LEDC_AUTO_CLK,
        .deconfigure = false,
    };
    esp_err_t result = ledc_timer_config(&timer);
    if (result != ESP_OK) {
        return result;
    }

    const ledc_channel_config_t yaw_channel = {
        .gpio_num = YAW_GPIO,
        .speed_mode = SERVO_PWM_MODE,
        .channel = YAW_PWM_CHANNEL,
        .intr_type = LEDC_INTR_DISABLE,
        .timer_sel = SERVO_PWM_TIMER,
        .duty = servo_policy_angle_to_duty(
            servo_policy_apply_trim(YAW_LIMITS.center,
                                    CONFIG_ROBOT_YAW_TRIM_DEGREES),
            CONFIG_ROBOT_YAW_INVERTED,
            SERVO_PWM_MAX_DUTY),
        .hpoint = 0,
        .sleep_mode = LEDC_SLEEP_MODE_NO_ALIVE_NO_PD,
        .flags.output_invert = 0,
    };
    const ledc_channel_config_t pitch_channel = {
        .gpio_num = PITCH_GPIO,
        .speed_mode = SERVO_PWM_MODE,
        .channel = PITCH_PWM_CHANNEL,
        .intr_type = LEDC_INTR_DISABLE,
        .timer_sel = SERVO_PWM_TIMER,
        .duty = servo_policy_angle_to_duty(
            PITCH_LIMITS.center, CONFIG_ROBOT_PITCH_INVERTED, SERVO_PWM_MAX_DUTY),
        .hpoint = 0,
        .sleep_mode = LEDC_SLEEP_MODE_NO_ALIVE_NO_PD,
        .flags.output_invert = 0,
    };
    result = ledc_channel_config(&yaw_channel);
    if (result == ESP_OK) {
        result = ledc_channel_config(&pitch_channel);
    }
    if (result != ESP_OK) {
        return result;
    }

    s_state.initialized = true;
    return ESP_OK;
}

esp_err_t servo_set_yaw(int16_t angle)
{
    return set_axis(YAW_PWM_CHANNEL,
                    angle,
                    &YAW_LIMITS,
                    CONFIG_ROBOT_YAW_TRIM_DEGREES,
                    CONFIG_ROBOT_YAW_INVERTED,
                    &s_state.yaw);
}

esp_err_t servo_set_pitch(int16_t angle)
{
    return set_axis(PITCH_PWM_CHANNEL,
                    angle,
                    &PITCH_LIMITS,
                    0,
                    CONFIG_ROBOT_PITCH_INVERTED,
                    &s_state.pitch);
}

servo_control_snapshot_t servo_control_get_snapshot(void)
{
    servo_control_snapshot_t snapshot = {
        .yaw_limits = YAW_LIMITS,
        .pitch_limits = PITCH_LIMITS,
    };
    if (s_mutex != NULL && xSemaphoreTake(s_mutex, portMAX_DELAY) == pdTRUE) {
        snapshot = s_state;
        xSemaphoreGive(s_mutex);
    }
    return snapshot;
}

esp_err_t look_center(void)
{
    esp_err_t result = servo_set_yaw(YAW_LIMITS.center);
    if (result == ESP_OK) {
        result = servo_set_pitch(PITCH_LIMITS.center);
    }
    return result;
}

esp_err_t look_left(void)
{
    return servo_set_yaw(YAW_LIMITS.minimum);
}

esp_err_t look_right(void)
{
    return servo_set_yaw(YAW_LIMITS.maximum);
}

esp_err_t look_up(void)
{
    return servo_set_pitch(PITCH_LIMITS.minimum);
}

esp_err_t look_down(void)
{
    return servo_set_pitch(PITCH_LIMITS.maximum);
}
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

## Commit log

2026-08-06 docs: publish hardware and mechanical reference
    [esp32-s3-robot-car.step]
2026-08-08 feat: add ESP32-S3 camera benchmark
2026-08-19 feat: archive D2 camera streaming experiment
2026-08-19 Revert "Merge pull request #3 from 39394480ke-sys/codex/archive-camera-d0-d1-d2"
    This reverts commit bf5e15fa76869dbf740335b2ad6dba9171ea3741, reversing
    changes made to 596b2115899387f7165dd6e9ab23bfb6d4f1a929.
    [app_main.c]
2026-08-19 Revert "Merge pull request #1 from 39394480ke-sys/codex/archive-d0-d1-camera-benchmark"
    This reverts commit 596b2115899387f7165dd6e9ab23bfb6d4f1a929, reversing
    changes made to 12ebb70f66ff5fc73e9dd651348337fa68915aa1.
    [app_main.c]
2026-08-21 feat: add Stage A robot control firmware
    Separate the 90-degree Web/API yaw coordinate from the installed mechanical center using an inverted output and a +14-degree trim. Preserve the documented hardware verification boundaries.
    [app_main.c, motor_control.c, motor_policy.c]
2026-08-21 fix(web): throttle pitch slider updates
2026-08-21 feat: add Stage B desktop idle behavior
    Add interruptible desktop idle modes, bounded expressions and gimbal gestures, Web controls, status fields, and policy coverage. The planned two-hour reset, heap, and servo-temperature validation was explicitly waived and remains unverified.
    [app_main.c, desktop_idle.c, desktop_idle_policy.c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]
